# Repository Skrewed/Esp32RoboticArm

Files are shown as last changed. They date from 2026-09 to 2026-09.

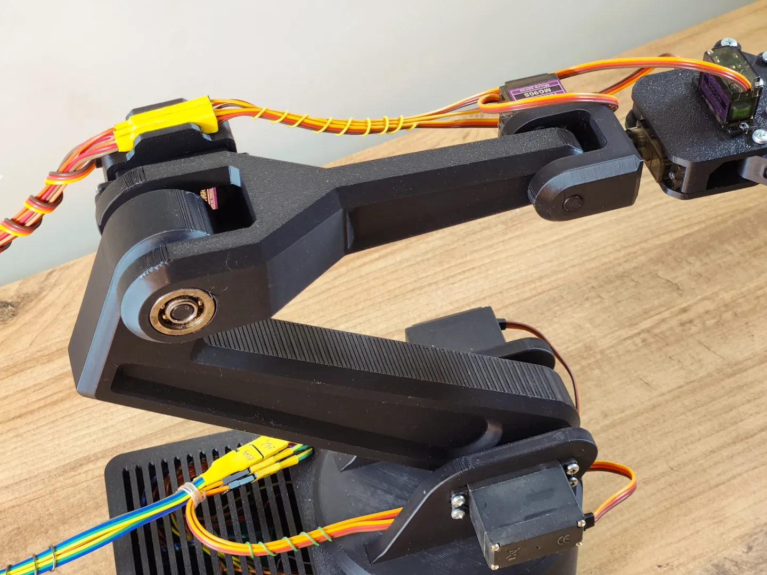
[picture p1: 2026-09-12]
artefatos/images/6.webp

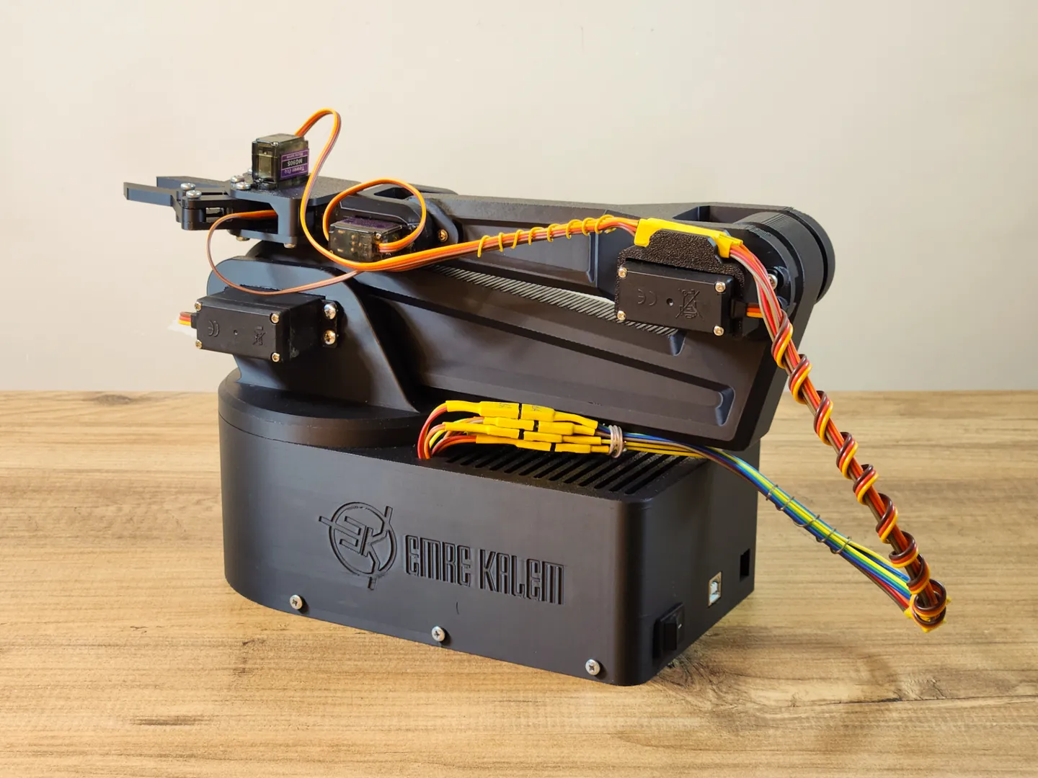
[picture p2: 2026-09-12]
artefatos/images/Auxiliaries_Model Pictures_7.webp

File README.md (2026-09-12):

# 🤖 Braço Robótico ESP32 - Sistema Completo de Controle Cinemático, IA & Dança Rítmica

Sistema integrado para controle de um **Braço Robótico de 7 Servomotores** com microcontrolador **ESP32 DevKit WROOM**, conversor de nível lógico **SN74HCT245N**, sistema de áudio digital **I2S (Microfones INMP441 e Alto-falante MAX98357A)**, backend assíncrono em **Python FastAPI** e interface web moderna com **Three.js (Visualizador 3D com Cinemática Inversa e Gimbal)**.

---

## 📋 Índice
1. [Visão Geral e Arquitetura](#-visão-geral-e-arquitetura)
2. [Guia Completo: Instalação e Execução em Outro Computador](#-guia-completo-instalação-e-execução-em-outro-computador)
   - [Softwares Necessários no Sistema Operacional](#1-softwares-necessários-no-sistema-operacional)
   - [Método 1: Inicialização Rápida em 1 Clique (`iniciar_servidor.bat`)](#método-1-inicialização-rápida-recomendado---1-clique)
   - [Método 2: Instalação Manual Passo a Passo (PowerShell / Terminal)](#método-2-instalação-manual-passo-a-passo-terminal-powershell)
   - [Configuração do Arquivo `.env`](#4-configurar-as-chaves-de-api-no-env)
3. [Configuração e Flash do Firmware ESP32 (`roboticArm.ino`)](#-configuração-e-flash-do-firmware-esp32-roboticarmino)
4. [Guia de Funcionalidades da Interface Web](#-guia-de-funcionalidades-da-interface-web)
   - [Conexão e Teste de IP do ESP32 & Alternância de Tema](#1-conexão-e-teste-de-ip-do-esp32--alternância-de-tema)
   - [Visualizador 3D & Gimbal Cinemático na Garra](#2-visualizador-3d--gimbal-cinemático-na-garra)
   - [Limitações Mecânicas Reais Anti-Crippling](#-limitações-mecânicas-reais-anti-crippling)
   - [Conversação por Voz com IA & Localização Sonora (DOA)](#3-conversação-por-voz-com-ia--localização-sonora-doa)
   - [Música & Dança Sincronizada aos Beats](#4-música--dança-sincronizada-aos-beats)
   - [Calibração de Home & Mapeamento Dinâmico de Pinos](#5-calibração-de-home--mapeamento-dinâmico-de-pinos)
5. [Esquema Elétrico e Power Delivery](#-esquema-elétrico-e-power-delivery)
6. [Solução de Problemas (Troubleshooting)](#-solução-de-problemas-troubleshooting)

---

## 🌟 Visão Geral e Arquitetura

O sistema opera em uma arquitetura cliente-servidor distribuída:

```mermaid
graph TD
    User([Usuário]) -->|Interface Web 3D / Áudio| Browser[Navegador Web / Three.js HUD]
    Browser <-->|WebSocket Telemetria / REST| Server[Servidor Python FastAPI :8000]
    Server <-->|HTTP REST / PCM Stream| ESP[ESP32 DevKit WROOM :80]
    
    subgraph "Nuvem de Inteligência Artificial"
        Server -->|Áudio Voz| Whisper[Groq Whisper large-v3-turbo]
        Server -->|Chat Contextual| GroqLLM[Groq GPT-OSS 20B]
        Server -->|Síntese de Voz| MistralTTS[Mistral Voxtral-mini-tts]
    end

    subgraph "Hardware do Braço Robótico"
        ESP -->|7x Sinais PWM 3.3V| LevelShifter[Conversor SN74HCT245N 5V]
        LevelShifter -->|PWM 5V Limpo| Servos[7x Servomotores 3x MG996R + 4x MG90S]
        MicI2S[2x Microfones INMP441 Estéreo] -->|I2S0 RX| ESP
        ESP -->|I2S1 TX| AmpI2S[Amplificador MAX98357A + Alto-falante]
        Power[Fonte 12V 10A + Step-Down 20A 5.2V] --> Servos
    end
```

---

## 💻 Guia Completo: Instalação e Execução em Outro Computador

Para configurar e rodar o projeto em um novo computador do zero (**Windows 10/11**, **Linux** ou **macOS**), instale os seguintes softwares essenciais:

### 1. Softwares Necessários no Sistema Operacional

| Software | Versão Recomendada | Função no Projeto | Instalação no Windows (PowerShell) | Instalação no Linux (Ubuntu/Debian) | Instalação no macOS (Homebrew) |
| :--- | :--- | :--- | :--- | :--- | :--- |
| **Python** | `3.10`, `3.11` ou `3.12` (64-bit) | Servidor FastAPI, processamento de áudio, cinemática e IA | `winget install Python.Python.3.12` | `sudo apt install python3 python3-venv python3-pip` | `brew install python` |
| **Node.js** | `v18+`, `v20+` ou `v22+` (LTS) | **Essencial:** Runtime JS exigido pelo `yt-dlp` para decodificar assinaturas e desafios do YouTube | `winget install OpenJS.NodeJS.LTS` | `sudo apt install nodejs` | `brew install node` |
| **FFmpeg** | `6.0+` ou `7.0+` | **Essencial:** Converte os formatos de áudio (MP3, WAV 16kHz, WebM e PCM para o ESP32) | `winget install Gyan.FFmpeg` | `sudo apt install ffmpeg` | `brew install ffmpeg` |
| **Git** | Qualquer versão moderna | Clonagem e controle de versão do repositório | `winget install Git.Git` | `sudo apt install git` | `brew install git` |
| **Arduino IDE** | `2.2+` ou `2.3+` | (Opcional) Apenas caso for compilar e regravar o firmware no ESP32 | `winget install Arduino.IDE` | Baixar AppImage oficial | `brew install --cask arduino-ide` |

> [!IMPORTANT]
> **Adicione os programas ao PATH do Sistema:**
> Ao instalar o Python manualmente no Windows pelo instalador `.exe`, certifique-se de marcar a caixa **"Add python.exe to PATH"**.
> 
> Para confirmar se tudo foi instalado e está acessível no terminal, abra um novo PowerShell/Terminal e execute:
> ```bash
> python --version   # Deve retornar Python 3.10, 3.11 ou 3.12
> node -v            # Deve retornar v18.x, v20.x ou v22.x
> ffmpeg -version    # Deve exibir a versão do FFmpeg
> git --version      # Deve exibir a versão do Git
> ```

---

### 2. Como Executar no Novo Computador

Você pode iniciar o projeto de duas formas: **automática (1 clique)** ou **manual (pelo terminal)**.

### Método 1: Inicialização Rápida (Recomendado - 1 Clique)
Na pasta raiz do projeto, basta dar **duplo clique no arquivo**:
```
iniciar_servidor.bat
```
O script automatizado irá:
1. Verificar se Python, Node.js e FFmpeg estão no PATH.
2. Criar automaticamente o ambiente virtual isolado (`venv`) caso ainda não exista.
3. Instalar/atualizar todas as bibliotecas necessárias listadas no `requirements.txt`.
4. Criar o arquivo `.env` a partir do template `.env.example`.
5. Abrir seu navegador padrão diretamente em `http://127.0.0.1:8000`.
6. Subir o servidor FastAPI na porta 8000 com live-reload.

---

### Método 2: Instalação Manual Passo a Passo (Terminal PowerShell)

#### 1. Clonar o Repositório
```powershell
git clone https://github.com/SEU_USUARIO/Esp32RoboticArm.git
cd Esp32RoboticArm
```

#### 2. Criar e Ativar o Ambiente Virtual Python
```powershell
python -m venv venv
.\venv\Scripts\activate
```
*(No Linux/macOS: `source venv/bin/activate`)*

#### 3. Instalar as Dependências do Python
```powershell
python -m pip install --upgrade pip
pip install -r requirements.txt
```

Principais pacotes incluídos no `requirements.txt`:
- `fastapi` e `uvicorn`: API REST de alta performance e servidor ASGI assíncrono.
- `websockets`: Telemetria bidirecional em tempo real a 30+ FPS.
- `httpx`: Comunicação HTTP assíncrona não bloqueante com o ESP32 e serviços de nuvem.
- `numpy` e `scipy`: Cálculos de Cinemática Inversa, Análise FFT rítmica e Localização Sonora (DOA via GCC-PHAT).
- `yt-dlp>=2026.8.19`: Extrator moderno de streaming do YouTube integrado com runtime Node.js.
- `edge-tts>=7.2.0`: Síntese de voz neural ultra-realista em Português do Brasil (100% sem sotaque).

#### 4. Configurar as Chaves de API no `.env`
Copie o template de exemplo:
```powershell
copy .env.example .env
```
Abra o `.env` gerado e configure suas chaves de API:
```ini
groq=gsk_SEU_TOKEN_GROQ_AQUI
voxtralArm=SEU_TOKEN_MISTRAL_AQUI
```
*(Se você não tiver chaves de nuvem no momento, todo o restante do sistema funciona normalmente: Simulador 3D, Cinemática Inversa, Gimbal, Sliders Manuais, Música & Dança e Pinos).*

#### 5. Iniciar o Servidor
```powershell
python -m uvicorn server.app:app --host 0.0.0.0 --port 8000 --reload
```
Acesse no seu navegador:
- No próprio computador: [http://127.0.0.1:8000](http://127.0.0.1:8000)
- Em qualquer outro smartphone ou notebook na mesma rede Wi-Fi: `http://IP_DO_SEU_PC:8000`

---

## ⚡ Configuração e Flash do Firmware ESP32 (`roboticArm.ino`)

### 1. Definir o IP e Wi-Fi no Início do `.ino`
Abra o arquivo `roboticArm.ino` no Arduino IDE. Logo nas primeiras linhas (linhas 40 a 60), localize a seção destacada:

```cpp
// ==============================================================================
//  >>> CONFIGURAÇÕES DE REDE & IP DO ESP32 (ALTERE AQUI ANTES DE FAZER O FLASH) <<<
// ==============================================================================

// 1. CONEXÃO COM SEU ROTEADOR WI-FI (MODO STATION)
const char* STA_SSID     = "SUA_REDE_WIFI";       // <-- Digite o nome da sua rede (2.4GHz)
const char* STA_PASSWORD = "SUA_SENHA_WIFI";     // <-- Digite a senha do seu Wi-Fi

// Defina 'true' para fixar o IP do ESP32 na sua rede local:
const bool  USAR_IP_ESTATICO_STA = true;

// IP Estático desejado para o ESP32 na sua rede local:
IPAddress   ESP32_IP_FIXO(192, 168, 1, 150);      // <--- DEFINE O IP DO ESP32 AQUI
IPAddress   ESP32_GATEWAY(192, 168, 1, 1);        // <--- IP do seu roteador
IPAddress   ESP32_SUBNET(255, 255, 255, 0);       // <--- Máscara de rede
IPAddress   ESP32_DNS(8, 8, 8, 8);                // <--- DNS do Google

// 2. REDE WI-FI PRÓPRIA CRIADA PELO ESP32 (MODO ACCESS POINT - AP)
const char* AP_SSID      = "BRACO_ESP32_AP";
const char* AP_PASSWORD  = "12345678";
IPAddress   AP_IP(192, 168, 4, 1);                // <--- IP padrão se conectar no AP direto
```

### 2. Configurações da Placa no Arduino IDE
No menu **Ferramentas** (Tools):
- **Placa (Board)**: `ESP32 Arduino -> ESP32 Dev Module`
- **Upload Speed**: `921600` (ou `115200` se o cabo USB for longo)
- **CPU Frequency**: `240MHz (WiFi/BT)`
- **Flash Frequency**: `80MHz`
- **Partition Scheme**: `Default 4MB with spiffs (1.2MB APP/1.5MB SPIFFS)` ou `Huge APP (3MB No OTA/1MB SPIFFS)`
- **Porta (Port)**: Selecione a porta COM correspondente ao seu ESP32 (ex: `COM3`, `COM5`).

### 3. Gravação (Upload)
1. Clique no botão **Carregar** (Upload / Ícone de Seta para a Direita).
2. Se a mensagem `Connecting.......` aparecer no console, pressione e segure o botão **BOOT** na placa ESP32 até iniciar a gravação.
3. Ao finalizar (`Done uploading`), abra o **Monitor Serial** (Ctrl+Shift+M) configurado em **115200 baud**.
4. Você verá a mensagem de inicialização exibindo o IP ativo atribuído:
   ```
   === BRAÇO ROBÓTICO ESP32 V8.0 INICIALIZANDO ===
   [Wi-Fi AP] Ponto de acesso próprio ativo: BRACO_ESP32_AP | IP: 192.168.4.1
   [Wi-Fi STA] Conectando a SUA_REDE_WIFI......
   [Wi-Fi STA] Conectado com sucesso!
   [Wi-Fi STA] IP ATRIBUÍDO AO ESP32: 192.168.1.150
   Servidor HTTP do ESP32 ativo na porta 80.
   ```

---

## 🖥️ Como Executar o Sistema

### 1. Iniciar o Servidor Python FastAPI
No terminal (dentro da pasta raiz do projeto):
```powershell
python -m uvicorn server.app:app --host 0.0.0.0 --port 8000 --reload
```

O terminal exibirá:
```
INFO:     Uvicorn running on http://0.0.0.0:8000 (Press CTRL+C to quit)
INFO:     Started server process
INFO:     Application startup complete.
```

### 2. Acessar a Interface Web
Abra seu navegador de preferência e acesse:
- **No próprio PC**: [http://127.0.0.1:8000](http://127.0.0.1:8000)
- **Pelo Smartphone ou Tablet na mesma rede Wi-Fi**: `http://IP_DO_SEU_COMPUTADOR:8000`

---

## 🎮 Guia de Funcionalidades da Interface Web

### 1. Conexão e Teste de IP do ESP32 & Alternância de Tema
Na barra superior do sistema:
- **Botão `☀️ Tema Claro / 🌙 Tema Escuro`**: Alterna instantaneamente entre o tema escuro industrial e um tema claro com contraste WCAG AA/AAA em todos os textos, cartões e botões. A cena 3D (Three.js), o piso e a neblina também se ajustam dinamicamente, e a preferência é salva no `localStorage` do navegador.
- **Campo `IP ESP32`**: Digite o IP configurado no firmware (ex: `192.168.1.150` ou `192.168.4.1` caso esteja no Access Point direto).
- **Botão `Testar Conexão` (ou tecla Enter)**: O backend realiza uma requisição de validação `/status` no ESP32.
  - Se online: o badge superior muda para verde: **● ESP32 Online (192.168.1.150)** e exibe aviso de sucesso.
  - Se offline: o sistema mantém o **● Simulador Virtual**, permitindo usar 100% das funções 3D, áudio e IA em modo de pré-visualização.

---

### 2. Visualizador 3D & Gimbal Cinemático na Garra
O visualizador renderiza fielmente todos os componentes CAD impressos em 3D:
- **Navegação de Câmera**:
  - **Botão Esquerdo do Mouse + Arrastar**: Rotacionar a câmera ao redor do braço.
  - **Botão Direito do Mouse + Arrastar**: Transladar (Pan) a cena.
  - **Roda do Mouse (Scroll)**: Zoom in e Zoom out (com iluminação balanceada e sem escurecimento de neblina).
- **Modelagem Realista da Garra, Punho e Servomotores**:
  - Todas as peças seguem o esquema real da montagem física ([`images/garra.png`](file:///c:/Users/Misha/Documents/GitHub/Esp32RoboticArm/images/garra.png)), com acabamento escuro industrial (`#1e293b`).
  - O punho `Bilek` conecta perfeitamente ao antebraço `On_Kol` com pino de articulação no Eixo X (Pitch) e base voltada para a frente.
  - A tampa superior `El_Ust.stl` assenta perfeitamente sobre os dedos e punho a $Y = +7.5\text{mm}$, fechando a estrutura da garra.
  - Servomotores micro MG90S modelados proceduralmente (carcaça azul-escura/metálica, engrenagem de latão e etiqueta roxa): um horizontal no punho para rotação da garra e um vertical na tampa superior para abertura/fechamento.
  - As pinças principais (`Parmak_2 X 2.stl`) e as bielas paralelas (`Parmak X 2.stl`) são montadas em par simétrico e espelhado, fechando no centro e abrindo paralelamente via rotação em tesoura no Eixo Y.
- **Controle Gimbal 3D com Cinemática Inversa Analítica Exata (IK)**:
  - O manipulador Gimbal está ancorado com precisão milimétrica **no ponto central de toque das pontas dos dedos da garra** (`clawTipTarget`), com erro posicional de **0.000 mm**.
  - **Permanência Absoluta na Ponta:** Ao soltar o Gimbal após uma iteração, o Gizmo **permanece fixado na ponta da garra**, permitindo que o usuário clique novamente lá embaixo e continue o movimento a partir daquele ponto exato.
  - **Proteção Anti-Snap (Zero 180° Snap):** O robô opera exclusivamente no semi-espaço frontal ($Z \ge 45\text{mm}$, azimute de $15^\circ$ a $165^\circ$), eliminando a singularidade que provocava o giro brusco de 180°.
  - **Proteção Anti-Enterramento e Anti-Colisão:** Altura mínima travada em $Y \ge 135\text{mm}$ sobre a base ($r \le 165\text{mm}$) e $Y \ge 35\text{mm}$ na bancada aberta.
  - **Limitações Mecânicas Reais Anti-Crippling (Anti-Auto-Interseção):**
    - **Cotovelo (`cotovelo`):** Estritamente limitado entre **$25^\circ$ e $105^\circ$** (acima de 105° o antebraço colide e penetra no braço).
    - **Ombro (`ombro`):** Limitado entre **$35^\circ$ e $145^\circ$** (evita colisão com a mesa giratória).
    - **Punho Pitch (`punho`):** Limitado entre **$35^\circ$ e $145^\circ$**.
    - **Base (`base_rotacao`):** Limitada entre **$15^\circ$ e $165^\circ$**.
    - **Raio Radial de Alcance Seguro:** Limitado entre $140\text{mm}$ e $380\text{mm}$.
  - **Barra de Espaço:** Pressione a barra de espaço enquanto arrasta o Gimbal para abrir ou fechar a garra rapidamente.
- **Sliders Manuais no HUD Direito**: Permitem o ajuste fino individual de cada junta com feedback de ângulo em graus e sliders limitados aos ranges mecânicos seguros.

---

### 3. Conversação por Voz com IA & Localização Sonora (DOA)
Na aba **IA Talk**:
1. **Seletor de Microfone**:
   - `Microfones do Braço (I2S - Seguir Usuário)`: Utiliza a matriz estéreo de microfones MEMS INMP441 instalados no braço.
   - `Microfone do Navegador`: Utiliza o microfone do seu computador/notebook.
2. **Localização Sonora (DOA - Direction of Arrival)**:
   - Quando o microfone do braço é usado, o algoritmo processa os canais Esquerdo e Direito com **ILD** (Interaural Level Difference) gerado pela barreira acústica física e **TDOA** (Time Difference of Arrival via GCC-PHAT a 16kHz).
   - O sistema calcula o ângulo relativo (-80° a +80°) e **gira automaticamente o servo da base (`base_rotacao`) na direção de quem estiver falando com o robô**!
   - Um badge visual `🎯 Voz detectada à Esquerda (+35°) -> Virando base para você!` surge na tela.
3. **Vozes Neurais em Português Brasileiro (Sem Sotaque)**:
   - **Antônio (`pt-BR-AntonioNeural`)**: Voz masculina nativa brasileira natural e fluida, sem nenhum sotaque estrangeiro.
   - **Francisca (`pt-BR-FranciscaNeural`)**: Voz feminina nativa brasileira de alta expressividade.
   - **Thalita (`pt-BR-ThalitaMultilingualNeural`)**: Opção feminina com entonação moderna.
   - **Paul (`en_paul_neutral`)**: Voz inglesa original da Mistral Voxtral (disponível para comparação).
   > [!NOTE]
   > A API oficial da Mistral Voxtral possui atualmente apenas 10 vozes pré-definidas em inglês (`en_us` e `en_gb`), o que causava pronúncia fonética com sotaque americano ao falar português. Além disso, a clonagem de vozes personalizadas na Mistral (`minhavoz.m4a`) está restrita a planos corporativos pagos (`HTTP 403`). A integração nativa do **Edge Neural TTS** solucionou esse problema com áudio brasileiro 100% natural, latência de ~1.2s e custo zero.
4. **Filtro de Ruído & Detecção Inteligente de Fala (VAD Anti-Teclado e Anti-Pássaros)**:
   - **Filtro Passa-Faixa Biquad (`bandpass` 300Hz - 3200Hz)**: Isola exclusivamente as frequências formantes da voz humana no Web Audio API. Corta agudos intensos (como cantos de pássaros externos de 4kHz a 8kHz) e ruídos de teclado/vibrações mecânicas (<200Hz e clicks secos).
   - **Slider de Sensibilidade / Limiar VAD (15 a 65, Padrão: 35)**: Ajustável diretamente na interface. Permite elevar o limiar em cômodos barulhentos para que cliques de teclas não mantenham o microfone aberto.
   - **Marcador Visual de Limiar**: O medidor de VU renderiza uma linha azul indicando o limiar de corte, facilitando calibrar a voz acima do ruído de fundo.
   - **Corte de Silêncio Rápido (800ms)**: Assim que o usuário termina a frase, o sistema encerra a gravação e envia o turno para a IA.
   - **Timer de Segurança (8s)**: Garante o auto-envio mesmo caso o usuário fale por tempo prolongado ou haja ruído contínuo.
   - **Botão `⏹️ Enviar` Imediato**: Permite forçar o envio da fala a qualquer instante com um clique, sem precisar aguardar o temporizador de silêncio.
5. **Pipeline Completo de Conversação**:
   - **Reconhecimento de Voz (STT)**: Groq Whisper (`whisper-large-v3-turbo`) em Português do Brasil.
   - **Raciocínio Contextual**: Groq Chat (`openai/gpt-oss-safeguard-20b`).
   - **Síntese de Voz (TTS)**: Síntese Neural Brasileira (Edge TTS / Mistral). O áudio é reproduzido tanto no navegador quanto transmitido via streaming PCM para o alto-falante I2S do braço, enquanto a garra faz gestos de fala sincronizados.

---

### 4. Música & Dança Sincronizada aos Beats
Na aba **Música & Dança**:
- **Download do YouTube**: Cole qualquer URL do YouTube e clique em `Baixar & Dançar`. O sistema extrai o áudio via `yt-dlp`.
- **Upload Local**: Envie seus próprios arquivos `.mp3` ou `.wav`.
- **Análise Rítmica Algorítmica**: O backend analisa o espectro de frequências, picos de transientes, ritmo e seções de energia (drops e calmaria).
- **Coreografia Procedural**: O robô executa movimentos sincronizados nos 7 servomotores a 25 FPS, alternando poses e gestos no tempo exato das batidas da música.

---

### 5. Calibração de Home & Mapeamento Dinâmico de Pinos
- **Botão `Bring Home`**: Retorna o braço imediatamente à postura segura de repouso (Home).
- **Personalizar Posição Home**: Permite definir um ângulo customizado para cada motor ou clicar em `Capturar Posição 3D Atual` para usar a pose corrente.
- **Mapeamento de Pinos ESP32 (`SN74HCT245N`)**: Abre uma janela com a pinagem de cada junta. Permite remapear os pinos GPIO diretamente via software sem necessidade de recompilar o firmware no Arduino IDE.
- **Parada de Emergência (`⏹️ Parada Geral`)**: Desliga instantaneamente as rotinas ativas de música e IA, interrompendo qualquer movimentação dos servos.

---

## ⚡ Esquema Elétrico e Power Delivery

O projeto foi projetado conforme as especificações rigorosas do **Descritivo Técnico - Esquema v8**:

### 1. Sistema de Alimentação (Power Delivery)
- **Fonte Chaveada 12V 10A (120W)**: Fornece alta margem de corrente e baixo aquecimento.
- **Módulo Step-Down 20A 300W regulado em 5.2V**:
  - Alimenta exclusivamente as linhas de alimentação dos 7 servomotores.
  - Tensão de 5.2V compensa a perda de carga nos cabos sob pico de torque dos servos MG996R.
- **Isolamento de Linhas**: O microcontrolador ESP32 é alimentado via cabo USB ou regulador 5V dedicado. **Todos os GNDs (Fonte, Step-Down, ESP32, Level Shifter e Servos) são unificados em um barramento comum**.

### 2. Conversor de Nível Lógico SN74HCT245N (3.3V -> 5.0V)
Os servomotores esperam pulsos PWM de amplitude 5V TTL. O conversor HCT245 atua como isolador e amplificador de sinal:
- **Pinos VCC**: 5.0V
- **Pino OE (Output Enable, pino 19)**: Conectado ao GND (sempre ativo).
- **Pino DIR (Direção, pino 1)**: Conectado ao VCC (direção A -> B).

### 3. Tabela Completa de Pinagem

| Junta / Periférico | Modelo | GPIO ESP32 | Entrada Level Shifter (A) | Saída Level Shifter (B) | Linha de Energia |
| :--- | :--- | :--- | :--- | :--- | :--- |
| **Garra Abertura** | MG90S | `GPIO 13` | Pino 2 (A1) | Pino 18 (B1) | 5.2V Step-Down |
| **Garra Rotação** | MG90S | `GPIO 14` | Pino 3 (A2) | Pino 17 (B2) | 5.2V Step-Down |
| **Ombro Master** | MG996R | `GPIO 27` | Pino 4 (A3) | Pino 16 (B3) | 5.2V Step-Down |
| **Cotovelo** | MG996R | `GPIO 26` | Pino 5 (A4) | Pino 15 (B4) | 5.2V Step-Down |
| **Base Rotação** | MG996R | `GPIO 25` | Pino 6 (A5) | Pino 14 (B5) | 5.2V Step-Down |
| **Ombro Slave** | MG90S | `GPIO 18` | Pino 7 (A6) | Pino 13 (B6) | 5.2V Step-Down |
| **Punho Pitch** | MG90S | `GPIO 19` | Pino 8 (A7) | Pino 12 (B7) | 5.2V Step-Down |
| **Mic INMP441 (WS)** | I2S0 RX | `GPIO 33` | Direto no ESP32 | - | 3.3V ESP32 |
| **Mic INMP441 (SCK)** | I2S0 RX | `GPIO 32` | Direto no ESP32 | - | 3.3V ESP32 |
| **Mic INMP441 (SD)** | I2S0 RX | `GPIO 35` (Input) | Direto no ESP32 | - | 3.3V ESP32 |
| **Alto-falante MAX98357A (LRC)**| I2S1 TX | `GPIO 21` | Direto no ESP32 | - | 5.0V Step-Down |
| **Alto-falante MAX98357A (BCLK)**| I2S1 TX | `GPIO 22` | Direto no ESP32 | - | 5.0V Step-Down |
| **Alto-falante MAX98357A (DIN)**| I2S1 TX | `GPIO 23` | Direto no ESP32 | - | 5.0V Step-Down |

---

## 🔧 Solução de Problemas (Troubleshooting)

### 1. ESP32 não responde no botão "Testar Conexão"
- Verifique no Serial Monitor do Arduino IDE (115200 baud) se o ESP32 conectou ao Wi-Fi e qual IP ele obteve.
- Certifique-se de que o computador onde o servidor FastAPI está rodando está conectado na **mesma rede Wi-Fi / roteador** que o ESP32.
- Caso não tenha roteador disponível no momento, conecte o Wi-Fi do seu computador na rede do próprio ESP32 (`BRACO_ESP32_AP`, senha `12345678`) e teste o IP `192.168.4.1`.

### 2. O microfone do navegador não ativa
- Em navegadores baseados no Chromium, o acesso ao microfone via `getUserMedia` requer conexão via `http://localhost`, `http://127.0.0.1` ou `https://`. Ao acessar de outro computador via IP local, use o modo `Microfones do Braço (I2S)`.

### 3. Servomotores tremendo ou reiniciando o ESP32
- Certifique-se de que o terra (GND) do Step-Down está firmemente conectado ao pino GND do ESP32.
- Meça com um multímetro a saída do Step-Down sob carga: a tensão não deve cair abaixo de 4.9V quando os 3 servos MG996R se movem simultaneamente.

### 4. Erro ao sintetizar áudio ou transcrever
- Verifique se o comando `ffmpeg -version` funciona no terminal.
- Certifique-se de que as chaves de API no arquivo `.env` estão preenchidas corretamente e possuem cotas ativas no provedor Groq e Mistral.

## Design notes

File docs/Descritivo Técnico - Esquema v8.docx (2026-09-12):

BRAÇO ROBÓTICO – 6º PERÍODO SISTEMAS DE INFORMAÇÃO, UEMG (2026)

Descritivo técnico de diagrama e componentes

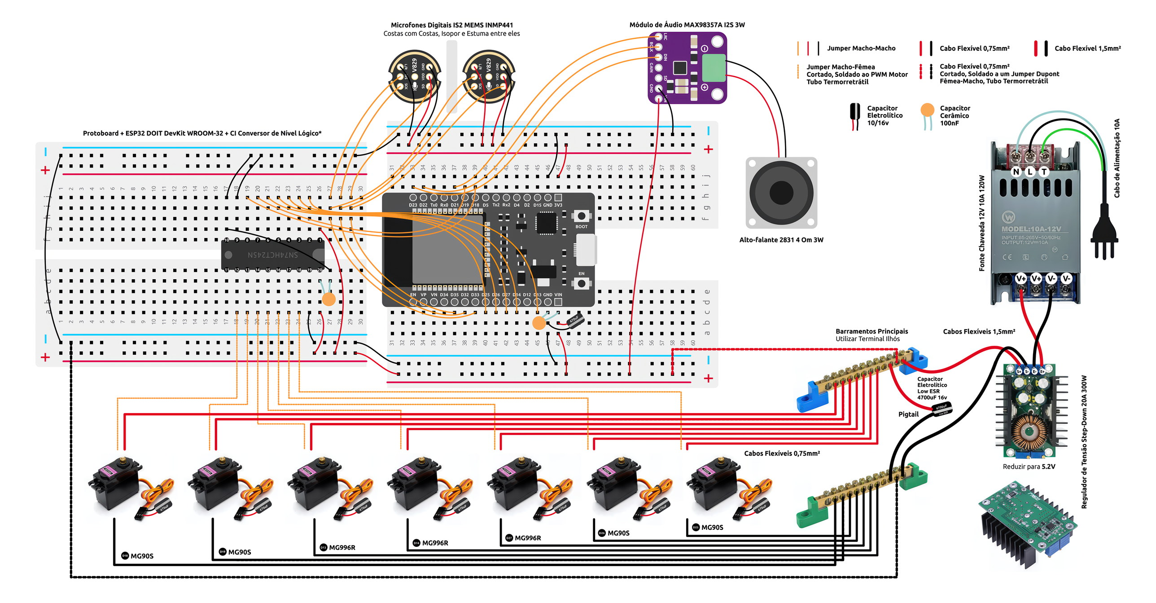
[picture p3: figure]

SISTEMA DE POTÊNCIA E DISTRIBUIÇÃO (POWER DELIVERY)

O desafio principal de controlar múltiplos servomotores é lidar com a alta demanda de corrente e os transientes gerados por eles. A arquitetura de energia foi desenhada para blindar o microcontrolador contra esses eventos.

Fonte Chaveada 12V 10A (120W):

Uma tensão de 12V na entrada permite transmitir energia com menor corrente do que se a fonte estivesse longe operando a 5V (reduzindo perdas pelo caminho). 10A (120W) oferecem um headroom (folga) gigantesco para o sistema, garantindo que a fonte não opere perto do seu limite térmico, o que aumenta a vida útil e reduz o ripple (ondulação) na saída.

Módulo Step-Down 20A 300W ajustado para 5.2V:

O Porquê do Módulo: Reduz eficientemente os 12V para a tensão de operação. A especificação de 20A garante que os picos de corrente (stall current) simultâneos de três motores MG996R (aprox. 2.5A cada) e dois MG90S sejam supridos sem que o regulador aqueça excessivamente ou desarme.

O Porquê dos 5.2V: Esta é uma técnica de mitigação de queda de tensão (voltage drop). Cabos e conectores possuem resistência intrínseca. Ao configurar para 5.2V na origem, garante-se que, sob carga máxima, a tensão que efetivamente chega aos terminais dos servos seja muito próxima aos 5.0V ideais, mantendo o torque máximo.

Barramentos Principais (Busbars de Cobre/Latão):

Trilhas de protoboard suportam, no máximo, cerca de 1A a 1.5A. Passar a alimentação dos motores pela protoboard a derreteria. Os barramentos atuam como um "nó" central de baixíssima resistência, distribuindo a alta corrente diretamente para os cabos dos servos.

Bitolas de Fios e Terminais Ilhós:

Cabos 1.5mm² (Fonte -> Step-Down -> Barramentos): Fios desta bitola suportam até ~15A com segurança e mínima resistência. São ideais para o tronco principal de energia.

Cabos 0.75mm² (Barramentos -> Servos): Flexíveis o suficiente para o roteamento nos eixos do braço robótico, mas espessos o bastante para lidar com picos de 2.5A a 3A sem aquecer ou causar queda de tensão significativa.

Uso de Terminais Ilhós (Tubulares): Fios de cobre multifilamentares, quando inseridos diretamente em bornes de parafusos (como no Step-Down, Fonte e barramentos Busbar), sofrem esmagamento irregular. Isso rompe filamentos, reduz a área de contato elétrico (aumentando a resistência e gerando calor) e cria o risco de fios soltos causarem curto-circuito. O ilhós consolida os filamentos, garantindo uma conexão mecânica robusta e condutividade adequada.

ESTABILIZAÇÃO E FILTRAGEM (REDE DE CAPACITORES)

Motores DC escovados e módulos de rádio (Wi-Fi/Bluetooth do ESP32) são fontes severas de ruído eletromagnético (EMI) e flutuações de tensão.

Capacitor Principal de Barramento: 4700µF 16V Low ESR:

Atua como o reservatório central de energia (Bulk Capacitance). Quando os motores dão partida, a corrente salta em milissegundos para cerca de 11A. Como o módulo Step-Down e os cabos têm um atraso natural para entregar essa potência, o capacitor supre a lacuna instantaneamente, cravando a tensão em 5.2V.

A característica "Low ESR" permite descarregar essa energia massiva sem o gargalo da resistência interna, evitando aquecimento e impedindo quedas bruscas de tensão (voltage sag) que resetariam o sistema.

Capacitores de Desacoplamento Local: 5x 470µF 16V Comuns:

Atuam como filtros locais (Bypass/Decoupling) e reserva de curtíssimo prazo. Posicionados nos chicotes dos servos, atendem ao pico inicial de cada motor nos primeiros microssegundos. Como motores DC geram muito ruído e pulsos reversos (back-EMF), usar capacitores "comuns" (com ESR maior) é vantajoso aqui: a resistência deles, somada à do cabo, cria um filtro amortecido (snubber RC/LC). Esse filtro "engole" a sujeira elétrica na origem, impedindo que o ruído viaje de volta e desestabilize a lógica do ESP32.

Filtro Composto no ESP32 (100nF Cerâmico + 470µF Eletrolítico entre GND e 5.2V da Proto):

O Porquê do Cerâmico (100nF): Capacitores cerâmicos respondem a frequências muito altas. Ele filtra o ruído de chaveamento (EMI) gerado pelo regulador Step-Down e pelos CIs lógicos, enviando esse ruído diretamente para o GND.

O Porquê do Eletrolítico (470µF): Lida com flutuações de baixa frequência. Evita que uma eventual oscilação remanescente na linha de 5.2V cause um Brownout Detector Reset (BOD) no ESP32 (tecnicamente poderia ser 100µF, mas optamos pelo de 470µF por precaução).

Capacitor Cerâmico 100nF no CI SN74HCT245N (Pino 20 ao Pino 10):

Conhecido como capacitor de desacoplamento ou bypass. Circuitos integrados digitais causam micro picos de corrente ao alternarem portas lógicas internamente em alta velocidade (MHz). Este capacitor garante a estabilidade exclusiva da alimentação do próprio chip.

CÉREBRO E CONVERSÃO LÓGICA (ESP32 E SN74HCT245N)

O ESP32 opera com lógica de 3.3V (nível Alto = 3.3V). Os servomotores estão alimentados com 5.2V. Pela especificação técnica, muitos conversos lógicos interpretam como nível Alto apenas tensões acima de 0.7 * VCC. Sendo VCC = 5.2V, o mínimo esperado para um sinal limpo seria 3.64V. Enviar os 3.3V do ESP32 diretamente para os servos potencialmente causaria perda de pulsos PWM, resultando em tremores (jitter) nos motores.

O Porquê da família HCT: Letras são importantes. A família "HCT" (High-Speed CMOS com entradas TTL) possui um limiar de transição diferente. Ele reconhece como nível Alto qualquer tensão acima de 2.0V. Assim, ele lê perfeitamente os 3.3V do ESP32 nos pinos de entrada (A) e amplifica o sinal PWM para sólidos 5.2V nos pinos de saída (B), entregando um controle impecável aos servos.

Além disso, a escolha do SN74HCT245N em detrimento de conversores lógicos bidirecionais comuns (como os baseados em MOSFETs para I2C) é uma decisão crítica para a integridade do PWM. Conversores bidirecionais dependem de resistores de pull-up para elevar a tensão do sinal (topologia open-drain), o que gera bordas de subida lentas e "arredondadas", especialmente quando submetidas à capacitância parasita de cabos mais longos. O HCT245, por sua vez, atua como um Line Driver unidirecional com saída ativa do tipo push-pull. Ele "empurra" e "puxa" a corrente ativamente, garantindo que o sinal em onda quadrada chegue aos motores com bordas de transição de estado perfeitamente retas e nítidas em alta frequência, eliminando definitivamente o risco de tremores (jitter) nos atuadores.

Mapeamento dos Servos entre ESP32 -> HCT245:

MG90S:

#1 D13: A1-IN > B1-OUT, pinos 2 (Entrada) e 18 (Saída)

#2 D14: A2-IN > B2-OUT, pinos 3 (Entrada) e 17 (Saída)

#3 D18: A6-IN > B6-OUT, pinos 7 (Entrada) e 13 (Saída)

#4 D19: A7-IN > B7-OUT, pinos 8 (Entrada) e 12 (Saída)

MG996R:

#1 D27: A3-IN > B3-OUT, pinos 4 (Entrada) e 16 (Saída)

#2 D26: A4-IN > B4-OUT, pinos 5 (Entrada) e 15 (Saída)

#3 D25: A5-IN > B5-OUT, pinos 6 (Entrada) e 14 (Saída)

INTERFACE SENSORIAL E ÁUDIO (I2S)

O barramento I2S (Inter-IC Sound) lida com áudio digital cru, sendo muito sensível a falhas de temporização (timing). O projeto dividiu fisicamente as vias de entrada e saída.

Conectados na linha 3.3V do ESP32 por ter limite de operação entre 1.8 e 3.3V.

Entrada: 2x Microfones MEMS INMP441 (Arranjo Estéreo):

O Porquê do posicionamento "Costas com Costas" (com isolamento): Ao usar dois microfones em direções opostas separados por uma barreira acústica (isopor/espuma), o sistema pode aplicar algoritmos de Beamforming ou cancelamento de ruído, determinando de qual lado vem a fonte sonora com base na diferença de fase/tempo do áudio (ideal para interações direcionais).

A Escolha dos Pinos I2S:

WS (D33) e SCK (D32): Clocks de sincronia.

SD (D35): O GPIO 35 do ESP32 é um pino exclusivo de entrada (Input-Only), não possuindo resistores de pull-up internos. Como o microfone apenas envia dados, alocar um pino Input-Only para o sinal SD é uma otimização excelente de arquitetura de portas, reservando pinos bidirecionais (como D2, D4) para atuadores.

L/R: Ligado ao GND sinaliza que aquele microfone atuará como Canal Esquerdo, enquanto o outro é conectado à linha VDD 3.3V do ESP32, sinalizando-o como Canal Direito.

VDD e GND: Alimentação simples na linha de 3.3V do ESP com retorno no próprio GND ESP.

Saída: Módulo MAX98357A e Alto-Falante (4 Ohms 3W):

Alimentação a 5.2V (Vindo da Proto): O MAX98357A suporta alimentação entre 2.5V e 5.5V. Alimentá-lo a partir dos 3.3V do ESP32 limitaria severamente a potência de saída (menos de 1W). Ao ligá-lo no barramento inferior de 5.2V, o amplificador consegue empurrar os 3W inteiros para o alto-falante de 4 Ohms, garantindo volume alto e sem clipping (distorção) por falta de tensão.

A Escolha dos Pinos I2S:

LRC (D21), BCLK (D22), DIN (D23): Estes pinos formam um grupo sequencial comum, suportam altas frequências de clock para o I2S e estão distantes fisicamente dos pinos geradores de PWM (como D13/D14), reduzindo o risco de crosstalk (interferência cruzada) de sinais no microcontrolador.

LISTA DE COMPONENTES ELETRÔNICOS:

1x ESP32 DOIT Devkit WROOM32

1x Protoboard 830 furos (seccionada na vertical e horizontal)

1x Kit 120x Jumpers Macho-Macho Macho-Fêmea e Fêmea-Fêmea

3x Servo Motor MG996R

4x Servo Motor MG90S

1x Kit Barramento Neutro e Terra 12 vias

1x Módulo de Áudio Amplificador MAX98357A I2S 3W QFN

1x Alto-falante 2831 4 Om 3W (Encapsulado, 15mm+ de profundidade)

1x Fonte Chaveada 12V 10A 120W

1x Regulador de Tensão DC Step-Down 20A 300W

2x Módulo Microfone INMP441

1x Circuito Integrado DIP-20 SN74HCT245N

1x Capacitor Eletrolítico 4700uF 16V+ (Low ESR se disponível)

8x Capacitor Eletrolítico 470uF 16V+

2x Capacitor Cerâmico 100nF (100kpf) 16V+

1x Cabo de Alimentação 10A 3 pinos (Fase, neutro e terra)

28x Conector tubular ilhós 0,75mm²

26x Conector tubular ilhós 1,5mm²

5 metros cabo flexível 0,75mm² Preto

5 metros cabo flexível 0,75mm² Vermelho

2 metros cabo flexível 1,5mm² Preto

2 metros cabo flexível 1,5mm² Vermelho

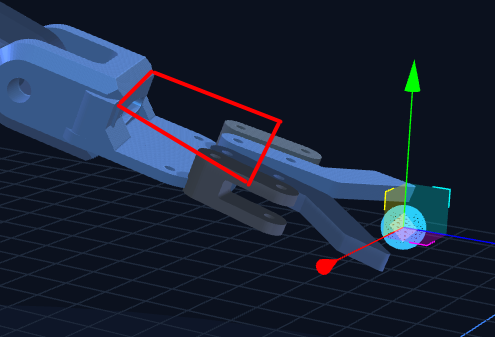
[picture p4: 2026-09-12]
artefatos/images/crop_red_box.png

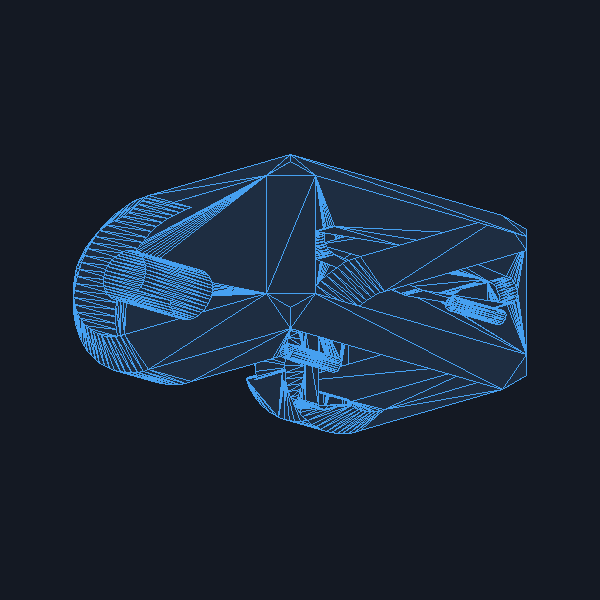
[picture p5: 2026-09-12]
artefatos/images/Bilek.stl.png

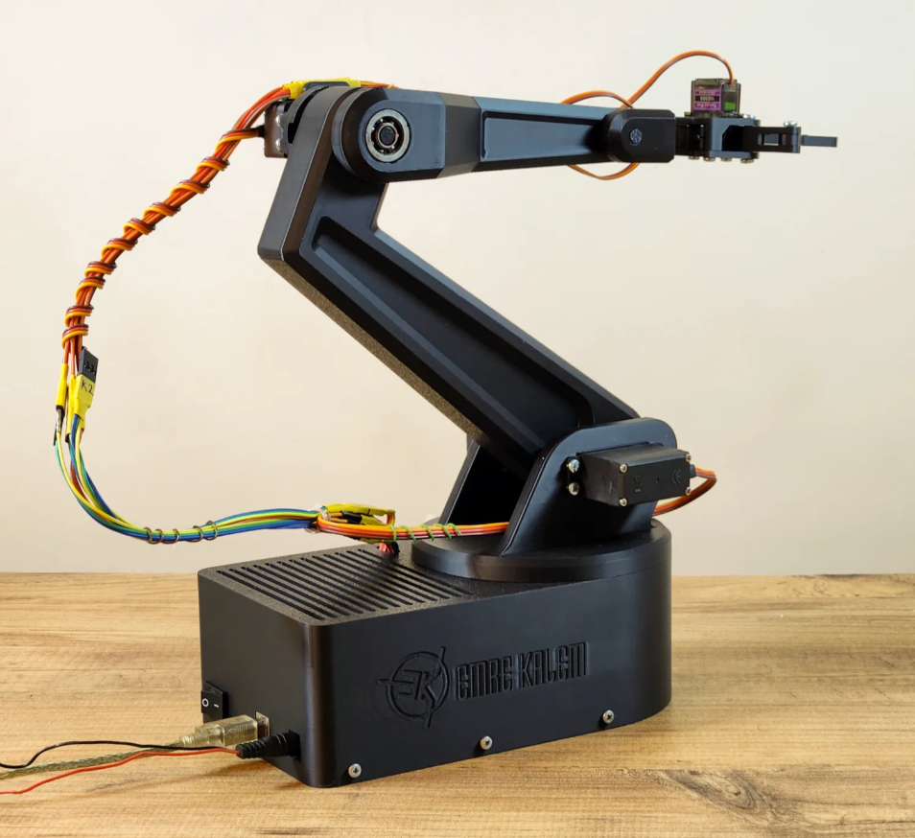
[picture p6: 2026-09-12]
artefatos/images/uaUws41d3I.png

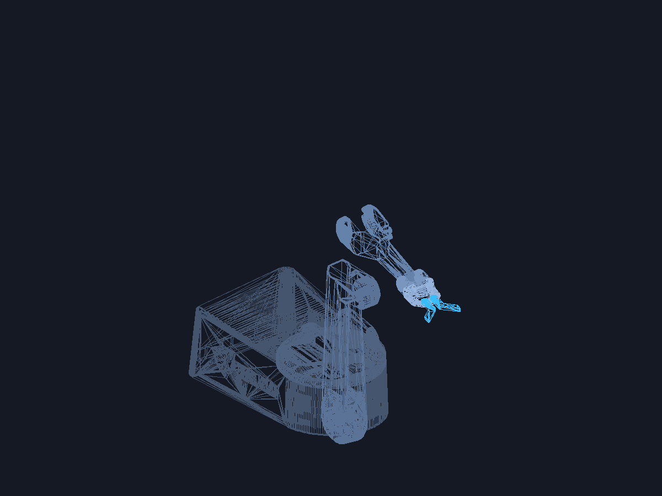
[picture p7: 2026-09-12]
artefatos/images/robot_arm_new_claw.png

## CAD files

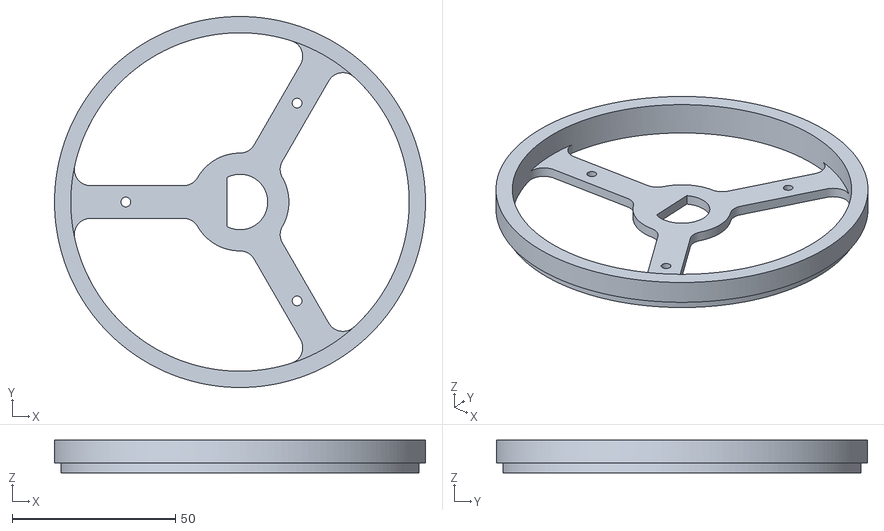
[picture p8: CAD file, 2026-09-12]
artefatos/3d/Tabla_Alt.stl
113.7 x 113.7 x 10.0

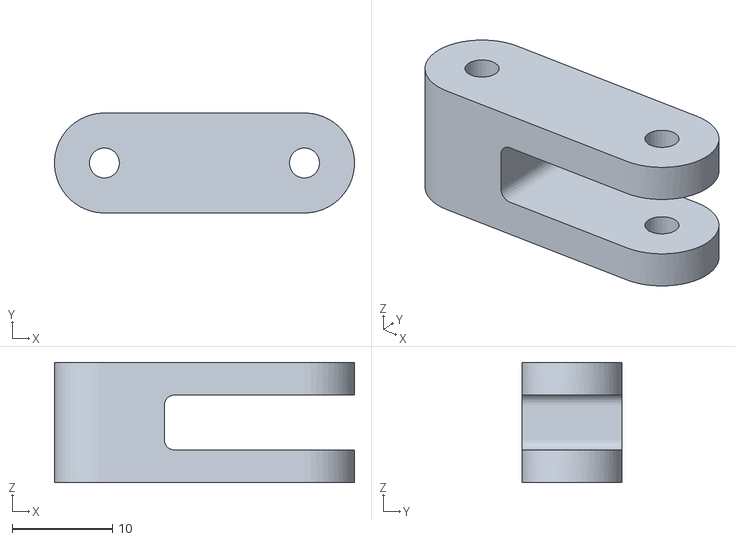
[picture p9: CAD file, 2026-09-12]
artefatos/3d/Parmak X 2.stl
30.0 x 10.0 x 12.0

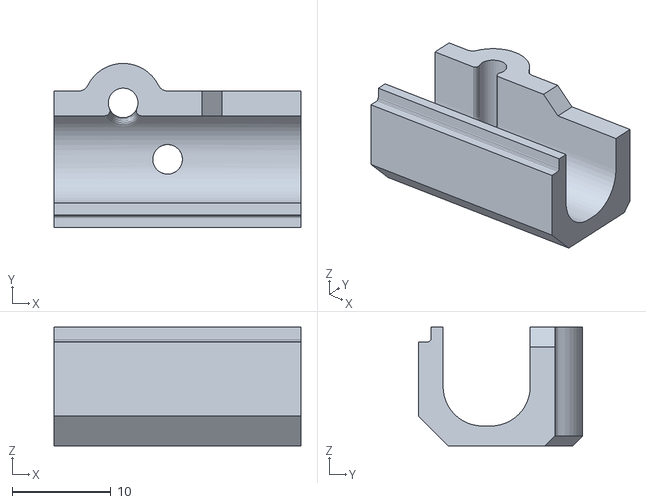
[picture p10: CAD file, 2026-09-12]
artefatos/3d/Jack_Cover.stl
25.0 x 16.6 x 12.0

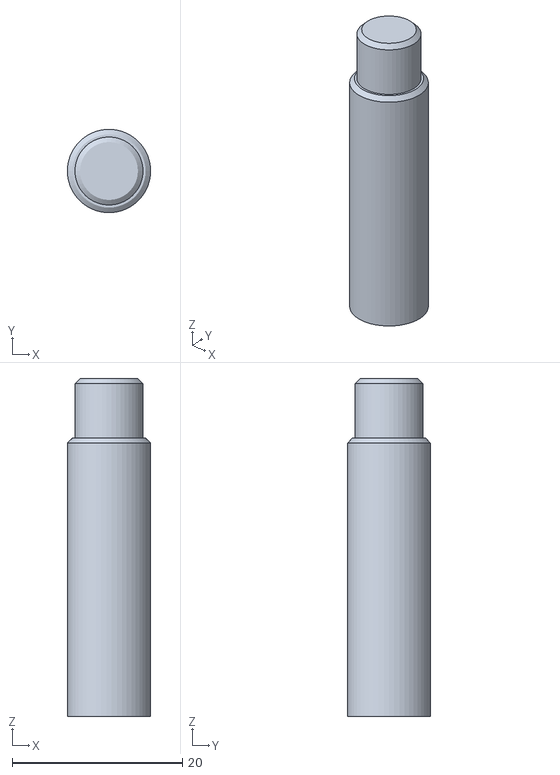
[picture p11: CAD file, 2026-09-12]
artefatos/3d/Mil_1.stl
9.80 x 9.78 x 39.8

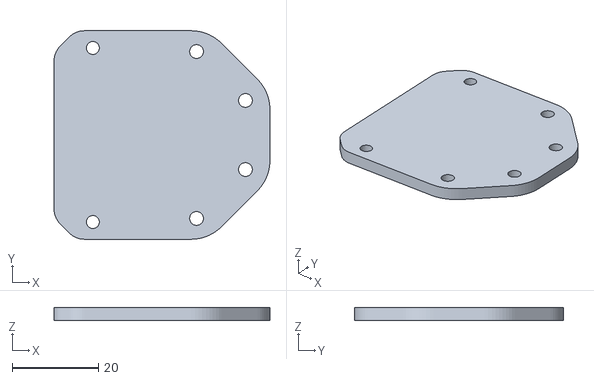
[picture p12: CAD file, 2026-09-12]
artefatos/3d/El.stl
50.0 x 48.3 x 3.00

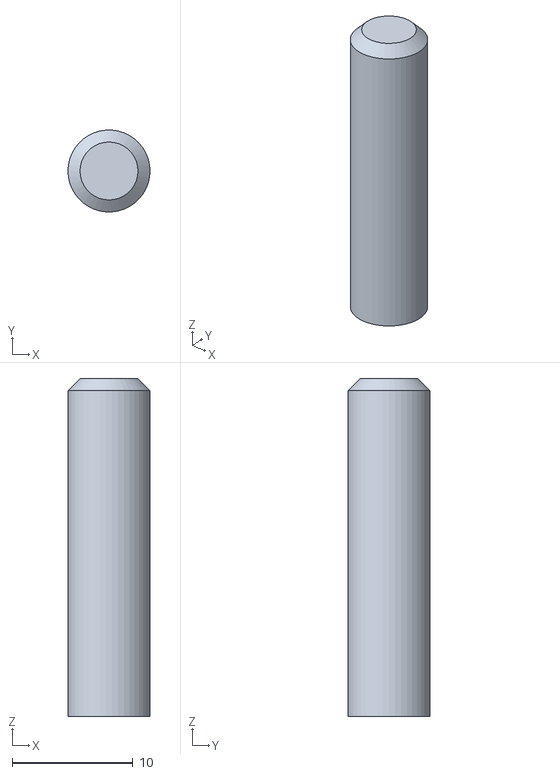
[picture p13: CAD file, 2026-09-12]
artefatos/3d/Mil_2.stl
6.80 x 6.78 x 28.0

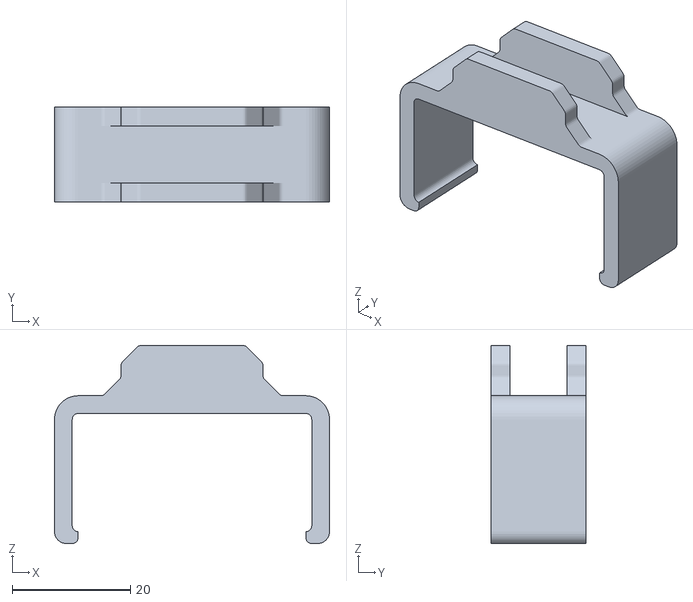
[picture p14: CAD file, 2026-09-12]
artefatos/3d/Servo_Cable_Holder.stl
46.5 x 16.0 x 33.5

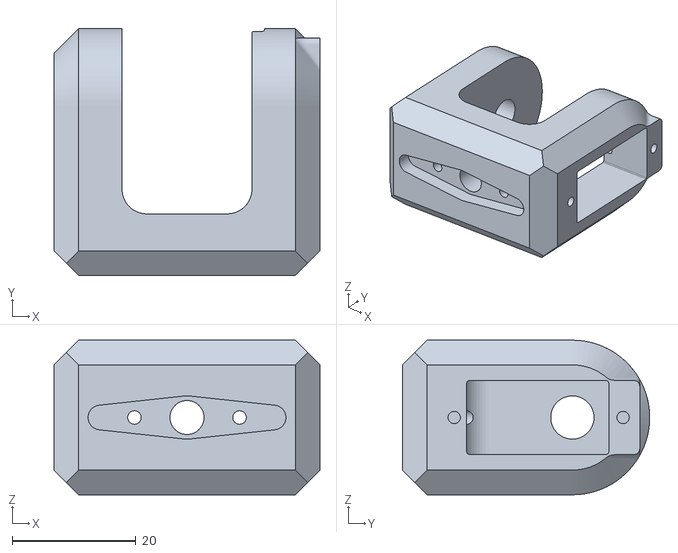
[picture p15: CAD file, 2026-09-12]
artefatos/3d/Bilek.stl
43.0 x 40.0 x 25.0

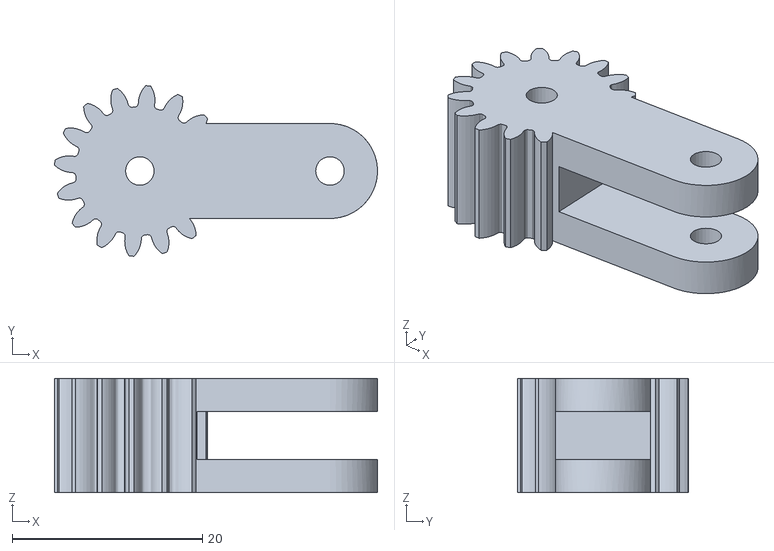
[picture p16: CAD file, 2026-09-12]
artefatos/3d/Parmak_Disli X 2.stl
34.0 x 18.0 x 12.0

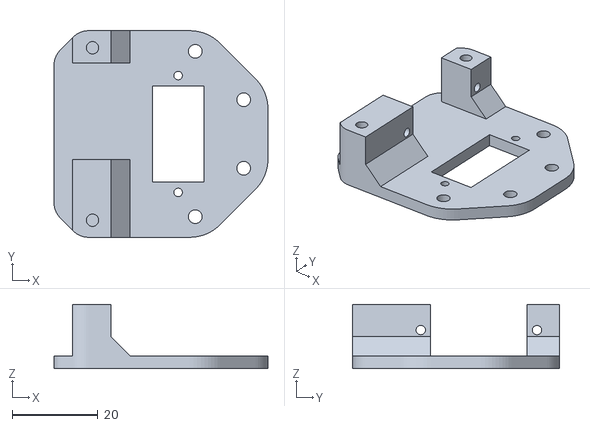
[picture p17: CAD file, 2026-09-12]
artefatos/3d/El_Ust.stl
50.0 x 48.3 x 15.0

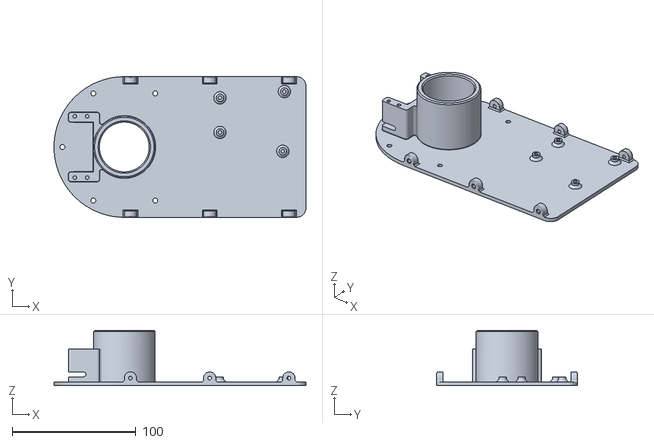
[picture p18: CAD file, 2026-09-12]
artefatos/3d/Alt_Kapak.stl
203.6 x 113.6 x 44.5

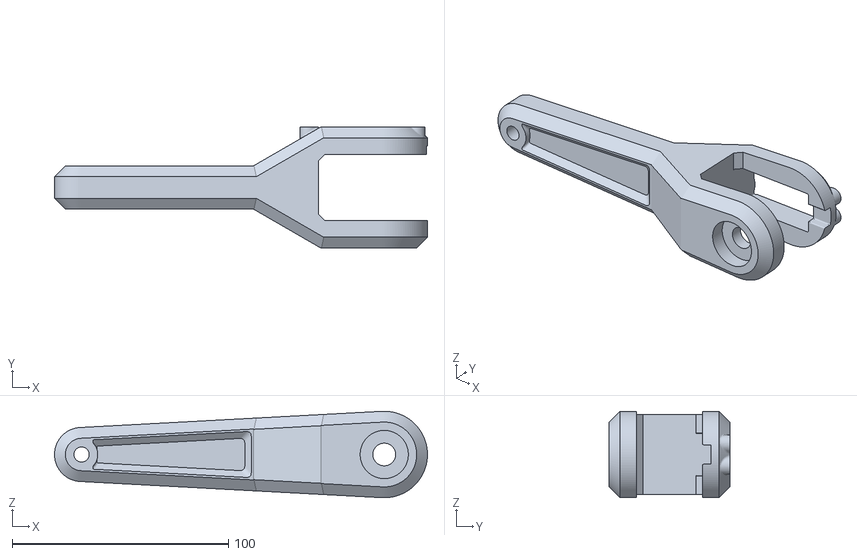
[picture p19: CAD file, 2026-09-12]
artefatos/3d/On_Kol.stl
172.5 x 56.0 x 40.0

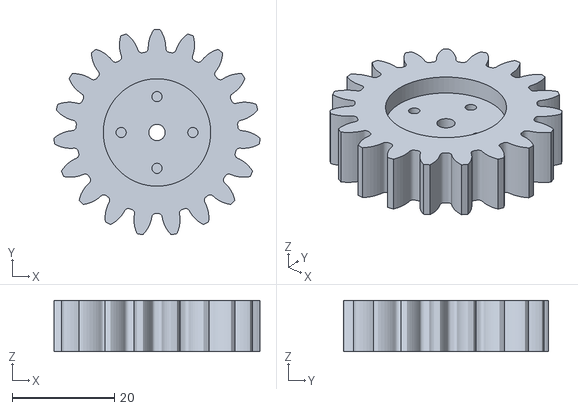
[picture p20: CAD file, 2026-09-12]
artefatos/3d/Servo_Disli.stl
40.3 x 40.1 x 10.0

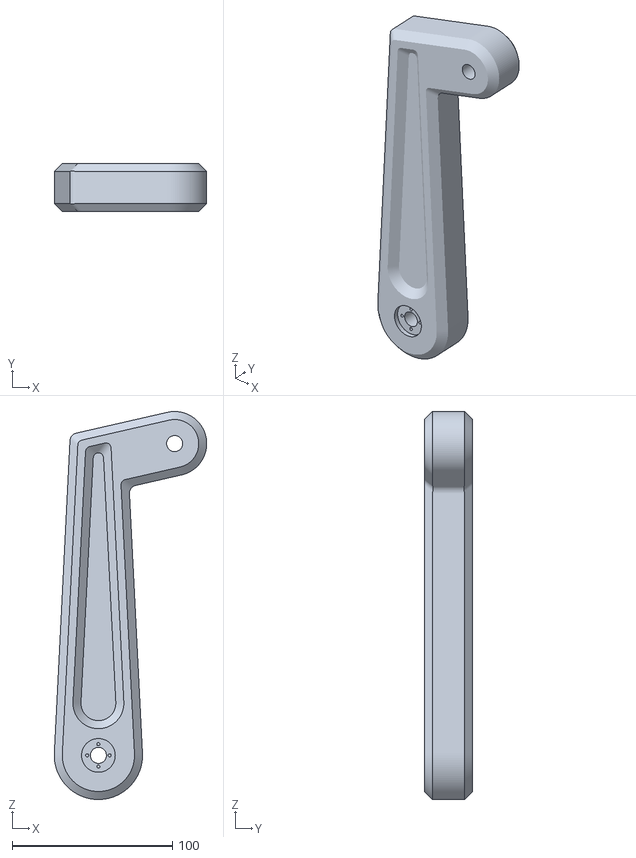
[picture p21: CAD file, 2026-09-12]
artefatos/3d/Alt_Kol.stl
95.0 x 30.0 x 241.8

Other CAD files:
artefatos/3d/Disli.stl
artefatos/3d/Parmak_2 X 2.stl
artefatos/3d/Arm.3mf
artefatos/3d/Alt_Kasa.stl
artefatos/3d/Alt_Govde.stl
artefatos/3d/Mil_3.stl
artefatos/3d/Mil_Disli.stl

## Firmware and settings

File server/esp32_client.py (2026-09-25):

import json
import time
import asyncio
import httpx
from server.config import (
    ESP32_DEFAULT_IP, ESP32_PORT, TECHNICAL_PINS,
    DEFAULT_HOME_CONFIG, DEFAULT_SERVO_LIMITS, ARM_CONFIG_FILE
)

class ESP32Client:
    def __init__(self):
        self.ip = ESP32_DEFAULT_IP
        self.port = ESP32_PORT
        self.is_connected = False
        self.is_simulated = True
        
        # System status
        self.system_enabled = True
        
        self.speed = 60
        self.is_moving = False
        self.home_config = dict(DEFAULT_HOME_CONFIG)
        
        # Pin mapping (Servo ID -> GPIO pin)
        self.pins_mapping = {
            "garra_abertura": 13,
            "garra_rotacao": 14,
            "ombro_slave": 18,
            "punho": 19,
            "base_rotacao": 25,
            "cotovelo": 26,
            "ombro_master": 27
        }

        # 7 Motors Limit ranges (0..180° physical range, centered at 90° [-90°..+90°])
        self.servo_limits = {k: dict(v) for k, v in DEFAULT_SERVO_LIMITS.items()}

        # Load persisted home configuration, pins, and servo limits if existing
        self._load_persisted_config()

        # Exact angles (in transit) vs target angles (commanded goal)
        self.current_angles = {k: float(v) for k, v in self.home_config.items()}
        self.target_angles = dict(self.home_config)

        self.last_check_time = 0.0
        self._client: httpx.AsyncClient | None = None

    def get_effective_shoulder_limits(self) -> dict:
        """
        Calculates the safe, coupled physical motion limits for the shoulder joint.
        The shoulder has 2 motors working together:
          - ombro_master (MG996R)
          - ombro_slave (MG90S, inverted: slave = 180 - master)
        To ensure neither motor binds or is forced against mechanical limits:
          eff_min = max(master_min, 180 - slave_max)
          eff_max = min(master_max, 180 - slave_min)
        """
        master = self.servo_limits.get("ombro_master", {"min": 35, "max": 145})
        slave = self.servo_limits.get("ombro_slave", {"min": 35, "max": 145})
        eff_min = max(master["min"], 180 - slave["max"])
        eff_max = min(master["max"], 180 - slave["min"])
        if eff_min > eff_max:
            eff_min = master["min"]
            eff_max = master["max"]
        return {"min": eff_min, "max": eff_max}

    def _load_persisted_config(self):
        """Loads saved home_config, pins mapping, and servo limits from disk if available."""
        if ARM_CONFIG_FILE.exists():
            try:
                with open(ARM_CONFIG_FILE, "r", encoding="utf-8") as f:
                    data = json.load(f)
                    if "esp32_ip" in data and isinstance(data["esp32_ip"], str) and data["esp32_ip"].strip():
                        self.set_ip(data["esp32_ip"], save=False)
                    if "home_config" in data and isinstance(data["home_config"], dict):
                        for k, v in data["home_config"].items():
                            if k in self.home_config:
                                self.home_config[k] = int(v)
                    if "pins" in data and isinstance(data["pins"], dict):
                        for k, v in data["pins"].items():
                            if k in self.pins_mapping:
                                self.pins_mapping[k] = int(v)
                    if "limits" in data and isinstance(data["limits"], dict):
                        for k, v in data["limits"].items():
                            if k in self.servo_limits and isinstance(v, dict):
                                min_v = max(0, min(180, int(v.get("min", self.servo_limits[k]["min"]))))
                                max_v = max(0, min(180, int(v.get("max", self.servo_limits[k]["max"]))))
                                if min_v > max_v:
                                    min_v, max_v = max_v, min_v
                                self.servo_limits[k]["min"] = min_v
                                self.servo_limits[k]["max"] = max_v
            except Exception as e:
                print(f"[ESP32Client] Erro ao carregar {ARM_CONFIG_FILE.name}: {e}")

    def _save_persisted_config(self):
        """Saves current home_config, pins mapping, servo limits, and esp32_ip to disk."""
        try:
            persisted_limits = {
                k: {"min": v["min"], "max": v["max"]}
                for k, v in self.servo_limits.items()
            }
            with open(ARM_CONFIG_FILE, "w", encoding="utf-8") as f:
                json.dump({
                    "esp32_ip": self.ip,
                    "home_config": self.home_config,
                    "pins": self.pins_mapping,
                    "limits": persisted_limits
                }, f, indent=2)
        except Exception as e:
            print(f"[ESP32Client] Erro ao salvar {ARM_CONFIG_FILE.name}: {e}")

    def _get_client(self) -> httpx.AsyncClient:
        if self._client is None or self._client.is_closed:
            self._client = httpx.AsyncClient(
                timeout=httpx.Timeout(1.0, connect=0.5),
                limits=httpx.Limits(max_keepalive_connections=5, max_connections=10)
            )
        return self._client

    def set_ip(self, raw_ip: str, save: bool = True) -> str:
        """Sanitizes raw IP/URL input, extracts port if specified, and persists."""
        ip = raw_ip.strip()
        if ip.startswith("http://"):
            ip = ip[7:]
        elif ip.startswith("https://"):
            ip = ip[8:]
        if ":" in ip:
            ip_part, port_part = ip.split(":", 1)
            ip = ip_part
            try:
                self.port = int(port_part.split("/")[0])
            except ValueError:
                pass
        if "/" in ip:
            ip = ip.split("/", 1)[0]
        self.ip = ip
        if save:
            self._save_persisted_config()
        return self.ip

    @property
    def base_url(self):
        return f"http://{self.ip}:{self.port}"
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

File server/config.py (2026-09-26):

import os
import sys
import shutil
from pathlib import Path

# Base paths
BASE_DIR = Path(__file__).resolve().parent.parent
ENV_PATH = BASE_DIR / ".env"
STATIC_DIR = BASE_DIR / "web"
MODELS_3D_DIR = (BASE_DIR / "artefatos" / "3d") if (BASE_DIR / "artefatos" / "3d").exists() else (BASE_DIR / "3d")
MODELS_3D_DIR.mkdir(parents=True, exist_ok=True)
UPLOADS_DIR = BASE_DIR / "server" / "media"
UPLOADS_DIR.mkdir(parents=True, exist_ok=True)
ARM_CONFIG_FILE = BASE_DIR / "server" / "arm_config.json"

# Ensure venv Scripts and standard Windows utility folders are in os.environ["PATH"]
VENV_SCRIPTS = BASE_DIR / "venv" / "Scripts"
EXTRA_PATH_DIRS = [
    str(VENV_SCRIPTS),
    r"C:\ffmpeg\bin",
    r"C:\Program Files\nodejs",
    r"C:\Program Files (x86)\nodejs"
]
for p in EXTRA_PATH_DIRS:
    if os.path.exists(p) and p.lower() not in os.environ.get("PATH", "").lower():
        os.environ["PATH"] = p + os.pathsep + os.environ.get("PATH", "")

def get_ffmpeg_executable() -> str:
    """Finds absolute path to ffmpeg executable with fallbacks."""
    which = shutil.which("ffmpeg")
    if which:
        return which
    candidates = [
        r"C:\ffmpeg\bin\ffmpeg.exe",
        r"C:\Program Files\ffmpeg\bin\ffmpeg.exe",
        r"C:\ProgramData\chocolatey\bin\ffmpeg.exe",
        os.path.expandvars(r"%LOCALAPPDATA%\Microsoft\WinGet\Packages\Gyan.FFmpeg_Microsoft.Winget.Source_8wekyb3d8bbwe\ffmpeg-9.0.2-full_build\bin\ffmpeg.exe"),
    ]
    for c in candidates:
        if os.path.exists(c):
            return c
    return "ffmpeg"

def get_ffmpeg_dir() -> str | None:
    """Returns directory containing ffmpeg binary for tools like yt-dlp."""
    exe = get_ffmpeg_executable()
    if os.path.isabs(exe) and os.path.exists(exe):
        return str(Path(exe).parent)
    which = shutil.which("ffmpeg")
    return str(Path(which).parent) if which else None

def get_node_executable() -> str | None:
    """Finds absolute path to node executable for yt-dlp JS runtime."""
    which = shutil.which("node")
    if which:
        return which
    candidates = [
        r"C:\Program Files\nodejs\node.exe",
        r"C:\Program Files (x86)\nodejs\node.exe",
    ]
    for c in candidates:
        if os.path.exists(c):
            return c
    return None

# Initialize API keys strictly from environment or .env file (NEVER hardcode secrets in source code)
GROQ_API_KEY = os.getenv("GROQ_API_KEY", os.getenv("groq", ""))
MISTRAL_API_KEY = os.getenv("MISTRAL_API_KEY", os.getenv("voxtralArm", ""))

# Load .env using python-dotenv if installed
try:
    from dotenv import load_dotenv
    if ENV_PATH.exists():
        load_dotenv(dotenv_path=ENV_PATH, override=True)
        GROQ_API_KEY = os.getenv("GROQ_API_KEY", os.getenv("groq", GROQ_API_KEY))
        MISTRAL_API_KEY = os.getenv("MISTRAL_API_KEY", os.getenv("voxtralArm", MISTRAL_API_KEY))
except ImportError:
    pass

# Direct parser fallback to ensure .env is always loaded even without python-dotenv
if ENV_PATH.exists():
    try:
        with open(ENV_PATH, "r", encoding="utf-8") as f:
            for line in f:
                line = line.strip()
                if "=" in line and not line.startswith("#"):
                    k, v = line.split("=", 1)
                    k = k.strip()
                    v = v.strip().strip("'\"")
                    if k in ["groq", "GROQ_API_KEY"] and v:
                        GROQ_API_KEY = v
                    elif k in ["voxtralArm", "MISTRAL_API_KEY"] and v:
                        MISTRAL_API_KEY = v
    except Exception as e:
        print(f"[Config] Erro ao ler arquivo .env: {e}")

if not GROQ_API_KEY:
    print("[Config] AVISO: Nenhuma chave 'groq' configurada no .env da raiz. As funções de IA por voz necessitam desta chave.")

# Server settings
SERVER_HOST = "0.0.0.0"
SERVER_PORT = 8000

# ESP32 settings
ESP32_DEFAULT_IP = "192.168.4.1" # Default AP IP or LAN IP
ESP32_PORT = 80

# Technical sheet pins (from Descritivo Técnico - Esquema v8)
# MG90S: D13, D14, D18, D19
# MG996R: D25, D26, D27
TECHNICAL_PINS = {
    "D13": {"gpio": 13, "type": "MG90S", "buffer": "A1-IN > B1-OUT (Pinos 2 e 18)", "default_joint": "garra_abertura"},
    "D14": {"gpio": 14, "type": "MG90S", "buffer": "A2-IN > B2-OUT (Pinos 3 e 17)", "default_joint": "garra_rotacao"},
    "D18": {"gpio": 18, "type": "MG90S", "buffer": "A6-IN > B6-OUT (Pinos 7 e 13)", "default_joint": "ombro_slave"},
    "D19": {"gpio": 19, "type": "MG90S", "buffer": "A7-IN > B7-OUT (Pinos 8 e 12)", "default_joint": "punho"},
    "D25": {"gpio": 25, "type": "MG996R", "buffer": "A5-IN > B5-OUT (Pinos 6 e 14)", "default_joint": "base_rotacao"},
    "D26": {"gpio": 26, "type": "MG996R", "buffer": "A4-IN > B4-OUT (Pinos 5 e 15)", "default_joint": "cotovelo"},
    "D27": {"gpio": 27, "type": "MG996R", "buffer": "A3-IN > B3-OUT (Pinos 4 e 16)", "default_joint": "ombro_master"},
}

# I2S Pin mappings
I2S_MIC_PINS = {
    "WS": 33,
    "SCK": 32,
    "SD": 35
}

I2S_SPK_PINS = {
    "LRC": 21,
    "BCLK": 22,
    "DIN": 23
}

# Default Joint limits and home angles
DEFAULT_HOME_CONFIG = {
    "base_rotacao": 90,
    "ombro": 90,
    "cotovelo": 90,
    "punho": 90,
    "garra_rotacao": 90,
    "garra_abertura": 90
}

# 7 Servo Motors Limit Specifications (0° to 180° physical range, centered at 90° [-90° to +90°])
DEFAULT_SERVO_LIMITS = {
    "base_rotacao": {
        "id": "base_rotacao",
        "name": "Base (Rotação)",
        "type": "MG996R",
        "default_pin": 25,
        "min": 15,
        "max": 165,
        "axis": "base"
    },
    "ombro_master": {
        "id": "ombro_master",
        "name": "Ombro (Motor Principal / Master)",
        "type": "MG996R",
        "default_pin": 27,
        "min": 35,
        "max": 145,
        "axis": "ombro",
        "role": "master"
    },
    "ombro_slave": {
        "id": "ombro_slave",
        "name": "Ombro (Motor Auxiliar / Slave)",
        "type": "MG90S",
        "default_pin": 18,
        "min": 35,
        "max": 145,
        "axis": "ombro",
        "role": "slave"
    },
    "cotovelo": {
        "id": "cotovelo",
        "name": "Cotovelo",
        "type": "MG996R",
        "default_pin": 26,
        "min": 25,
        "max": 105,
        "axis": "cotovelo"
    },
    "punho": {
        "id": "punho",
        "name": "Punho (Inclinação / Pitch)",
        "type": "MG90S",
        "default_pin": 19,
        "min": 35,
        "max": 145,
        "axis": "punho"
    },
    "garra_rotacao": {
        "id": "garra_rotacao",
        "name": "Garra (Rotação / Roll)",
        "type": "MG90S",
        "default_pin": 14,
        "min": 0,
        "max": 180,
        "axis": "garra_rotacao"
    },
    "garra_abertura": {
        "id": "garra_abertura",
        "name": "Garra (Abertura / Pinça)",
        "type": "MG90S",
        "default_pin": 13,
        "min": 45,
        "max": 135,
        "axis": "garra_abertura"
    }
}

SERVO_LIMITS = DEFAULT_SERVO_LIMITS

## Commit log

2026-09-12 Sistema de Controle Web
    [Alt_Govde.stl, Alt_Kapak.stl, Alt_Kasa.stl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]
2026-09-25 Update Posição e Velocidade Servos
2026-09-25 Ajuste método de conexão
2026-09-26 feat: aumento da velocidade padrão dos cervo motores.
2026-09-26 fix: aprimora cinematica, estabilidade do Wi-Fi e sincronia do motor de danca
    Refatoracao de diversas funcionalidades e correcao de logicas criticas de movimentacao:
    - Firmware (roboticArm.ino):
    - Correcao do mapeamento de angulo para pulso PWM. O servo agora respeita os limites via clamping, garantindo precisao 1:1 fisica sem distorcer as rotacoes originais.
    - Resolvido bug de instabilidade no Access Point: o robo nao fica mais preso escaneando redes (background scanning) quando o modo Station falha. O STA e automaticamente cortado para estabilizar 100% o modo AP.
    - Renderizacao 3D e Cinematica (arm_3d.js):
    - Remocao dos fatores artificiais de escalonamento (*0.8) do visualizador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
    [config.py, roboticArm.ino]
